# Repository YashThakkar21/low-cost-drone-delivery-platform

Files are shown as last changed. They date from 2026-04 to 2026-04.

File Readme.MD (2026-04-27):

# Low-Cost Drone Delivery Platform

A modular, open-source payload delivery add-on for commodity drone platforms. Designed and evaluated as part of an independent work project at Princeton University.

## Overview

This system attaches to an existing drone airframe and autonomously releases a payload when the drone descends to within one foot of the ground, detected via an HC-SR04 ultrasonic sensor. Two door mechanisms are provided and evaluated: a conventional hinged door and a sliding door.

| Mechanism | Success Rate | Servo | Flight Tested |
|---|---|---|---|
| Hinged door | 28% (7/25) | 1× MG996R | No |
| Sliding door | 84% (21/25) | 2× SG90 | Yes (8/10) |

The sliding door is the recommended design.

## Repository Structure

```
low-cost-drone-delivery-platform/
├── written_final_report.pdf    # Full research paper
├── conventional_door.ino       # Arduino firmware for hinged door
├── sliding_door.ino            # Arduino firmware for sliding door
├── payload_cad_files/          # Payload enclosure (upper + lower modules)
├── hinged_door_cad_files/      # Hinged door mechanism CAD
├── sliding_door_cad_files/     # Sliding door mechanism CAD (modified panels)
└── component_mounts_cad_files/ # Arduino/breadboard mount, sensor case
```

## Hardware Requirements

| Component | Quantity |
|---|---|
| Drone with landing gear rails (e.g. Holybro X500 V2) | 1 |
| Arduino Uno | 1 |
| HC-SR04 ultrasonic sensor | 1 |
| SG90 servo motor (sliding door) | 2 |
| MG996R servo motor (hinged door) | 1 |
| 9V battery + connector | 1 |
| PLA filament (for 3D printing) | — |

## Setup

1. **Print** all CAD files in `payload_cad_files/`, `sliding_door_cad_files/`, and `component_mounts_cad_files/` using standard PLA.
2. **Assemble** the two-module enclosure: seat the Arduino and breadboard in the upper module, install the door mechanism in the lower module, and connect via the screw joint.
3. **Wire** the HC-SR04 to Arduino pins 7 (Trig) and 8 (Echo). Connect SG90 servos to pins 9 and 10. Power via 9V battery.
4. **Flash** `sliding_door.ino` to the Arduino using the Arduino IDE.
5. **Mount** the enclosure onto the drone's landing gear arms using the printed rail mount.

The door triggers automatically when the sensor reads ≤ 30.48 cm (1 ft) from the ground and closes after 10 seconds.

## Flight Platform

Any drone capable of carrying the payload system (~1.4 lb) can be used. This project was developed and tested on the **Holybro X500 V2** with a **Pixhawk 6C** running **PX4 firmware**, configured via **QGroundControl**.

## Paper

Full design details, evaluation methodology, and results are available in [`written_final_report.pdf`](./written_final_report.pdf). Topics covered include the iterative CAD design process (7 enclosure versions), bench reliability testing, flight trials, cost analysis, and a comparison against existing commercial and open-source platforms.

## License

Open-source. All CAD files and firmware are free to use, modify, and distribute.

---

*Princeton University — Department of Computer Science — Spring 2026*  
*Advisor: Professor David August*

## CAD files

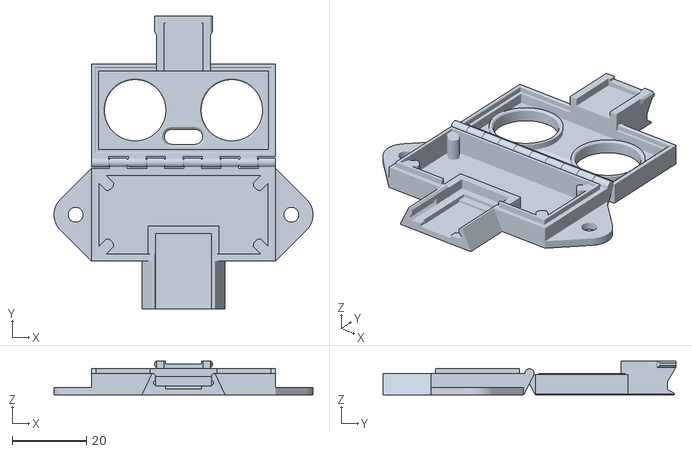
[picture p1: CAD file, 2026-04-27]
component_mounts_cad_files/ultrasonic_sensor_holder.stl
69.7 x 78.7 x 9.10

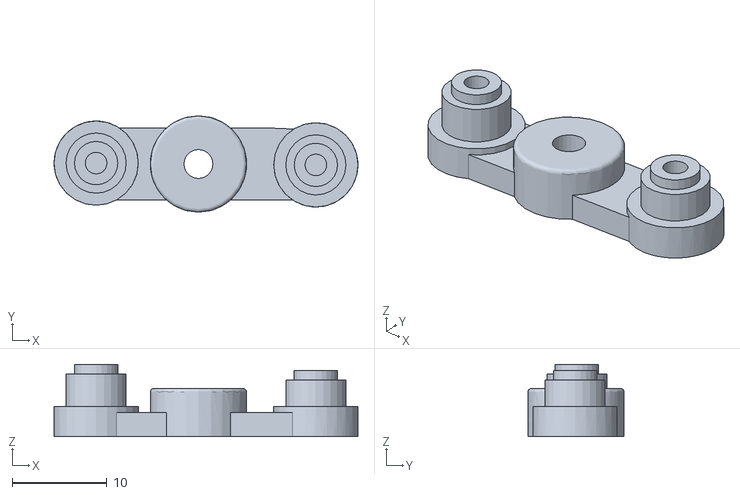
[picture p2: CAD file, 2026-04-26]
hinged_door_cad_files/output_arm.stl
32.1 x 10.2 x 7.62

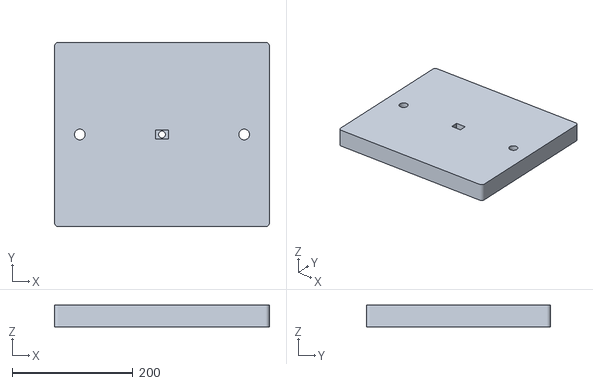
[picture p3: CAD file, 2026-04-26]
payload_cad_files/drone_mount.stl
355.6 x 304.8 x 35.6

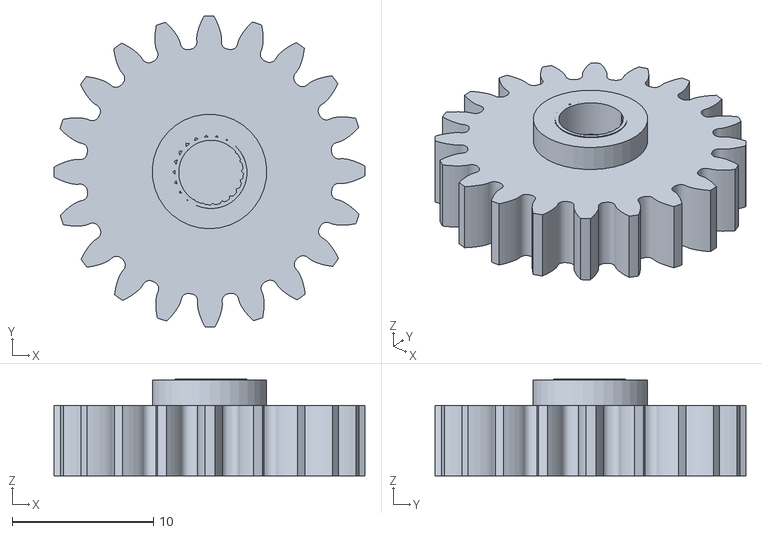
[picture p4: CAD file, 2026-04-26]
sliding_door_cad_files/gear.stl
22.0 x 22.0 x 6.86

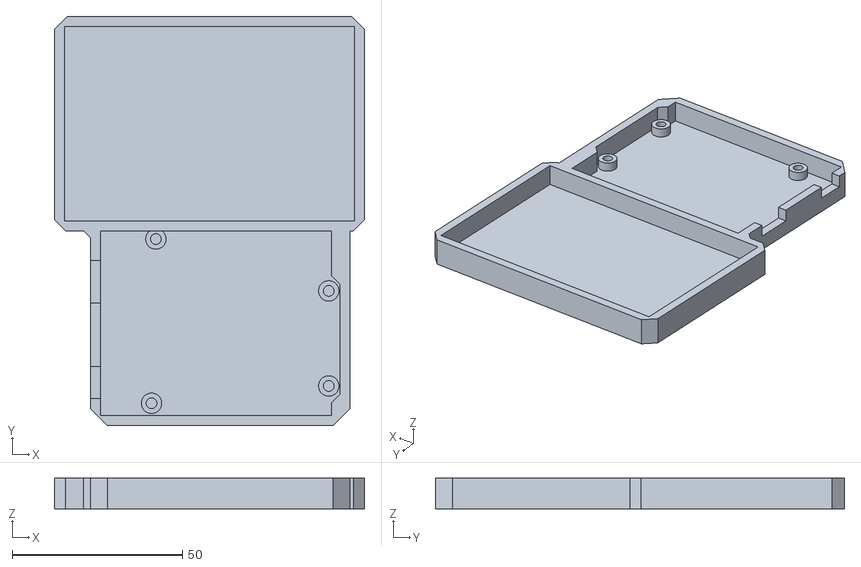
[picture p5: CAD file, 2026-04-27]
component_mounts_cad_files/Arduino_and_breadboard_holder.stl
91.1 x 120.2 x 9.00

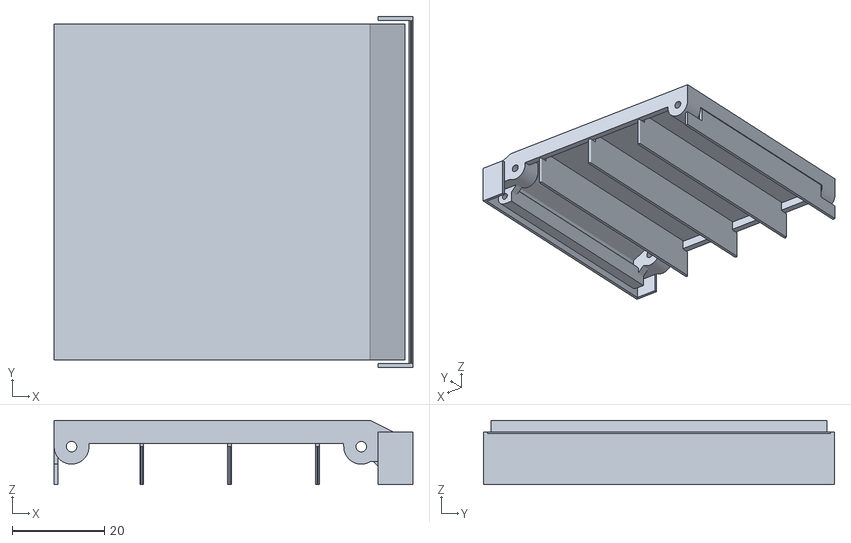
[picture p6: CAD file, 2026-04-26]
hinged_door_cad_files/door.stl
77.9 x 76.2 x 14.0

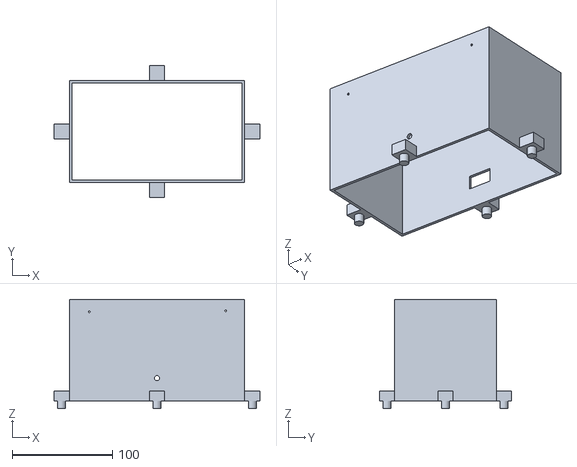
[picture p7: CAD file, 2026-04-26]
payload_cad_files/payload_sliding_bottom_module.stl
205.7 x 132.1 x 109.2

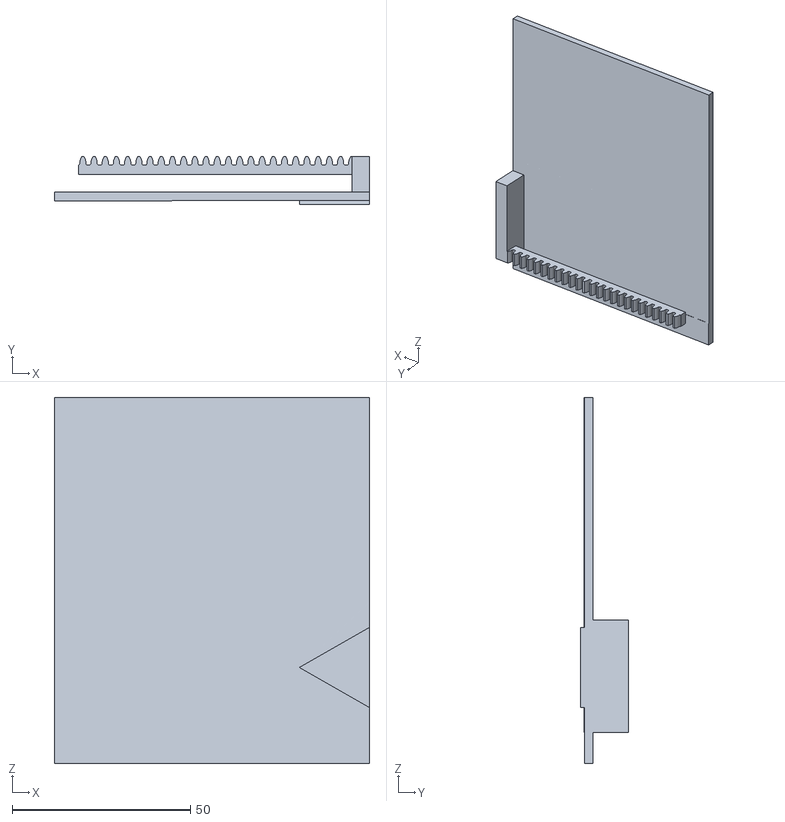
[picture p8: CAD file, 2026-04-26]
sliding_door_cad_files/door.stl
88.4 x 13.3 x 102.6

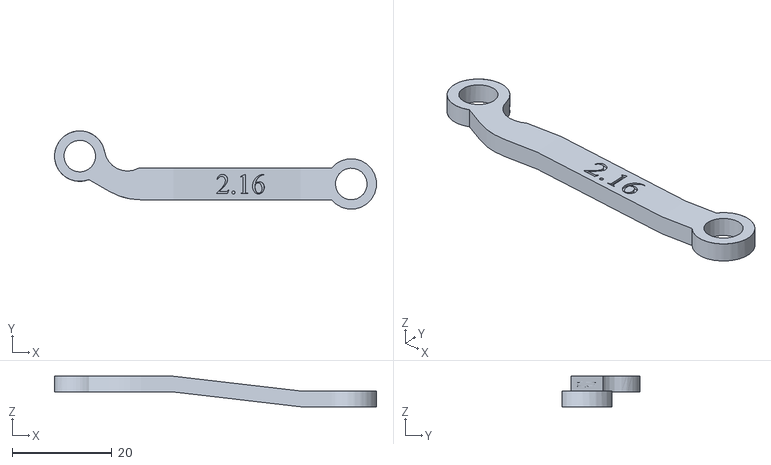
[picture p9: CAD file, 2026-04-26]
hinged_door_cad_files/right_support_arm.STL
64.7 x 15.7 x 6.13

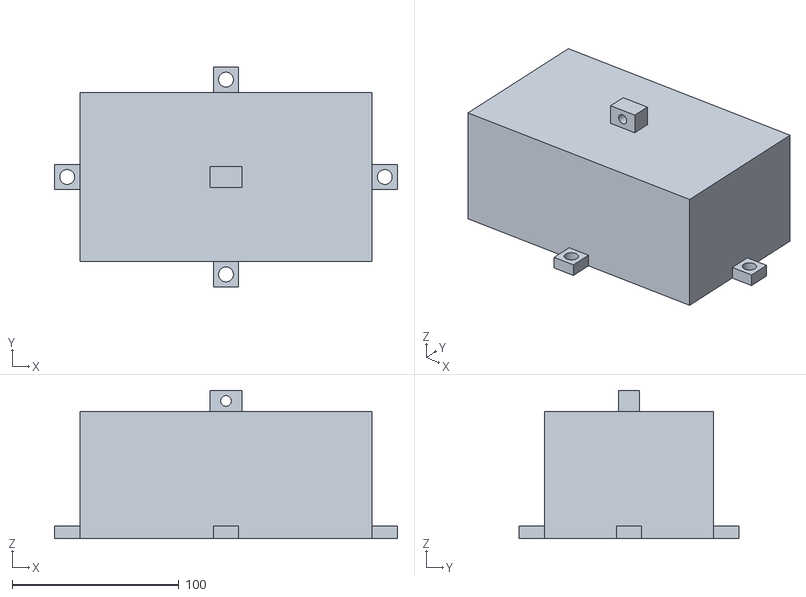
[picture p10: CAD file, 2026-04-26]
payload_cad_files/payload_top_module.stl
205.7 x 132.1 x 88.9

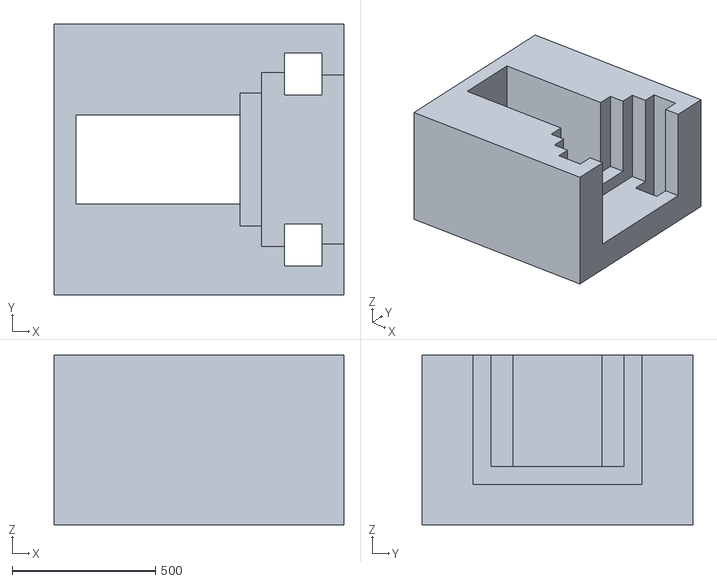
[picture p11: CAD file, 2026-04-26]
sliding_door_cad_files/motor_mount.stl
1010.9 x 945.1 x 591.8

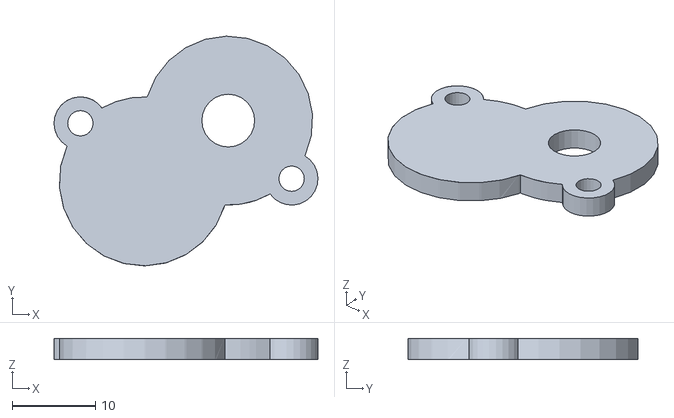
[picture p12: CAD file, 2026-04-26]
hinged_door_cad_files/gear_case_cover.stl
31.7 x 27.6 x 2.54

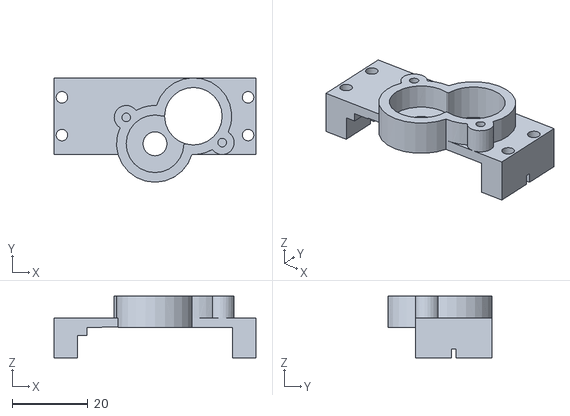
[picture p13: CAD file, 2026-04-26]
hinged_door_cad_files/gear_case.stl
53.5 x 27.6 x 16.4

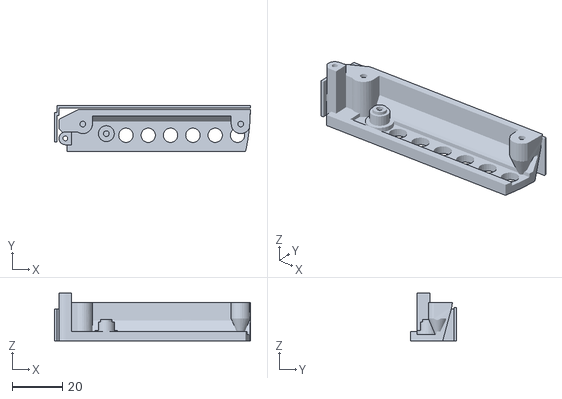
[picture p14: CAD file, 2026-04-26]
hinged_door_cad_files/front_l.stl
78.0 x 18.1 x 19.0

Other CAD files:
payload_cad_files/payload_hinged_bottom_module.stl
hinged_door_cad_files/arm_support.stl
hinged_door_cad_files/double_bone.stl
hinged_door_cad_files/single_bone.stl
hinged_door_cad_files/front_r.stl
hinged_door_cad_files/gear.stl
hinged_door_cad_files/hinges.stl
hinged_door_cad_files/left_support_arm.STL
hinged_door_cad_files/output_gear.stl

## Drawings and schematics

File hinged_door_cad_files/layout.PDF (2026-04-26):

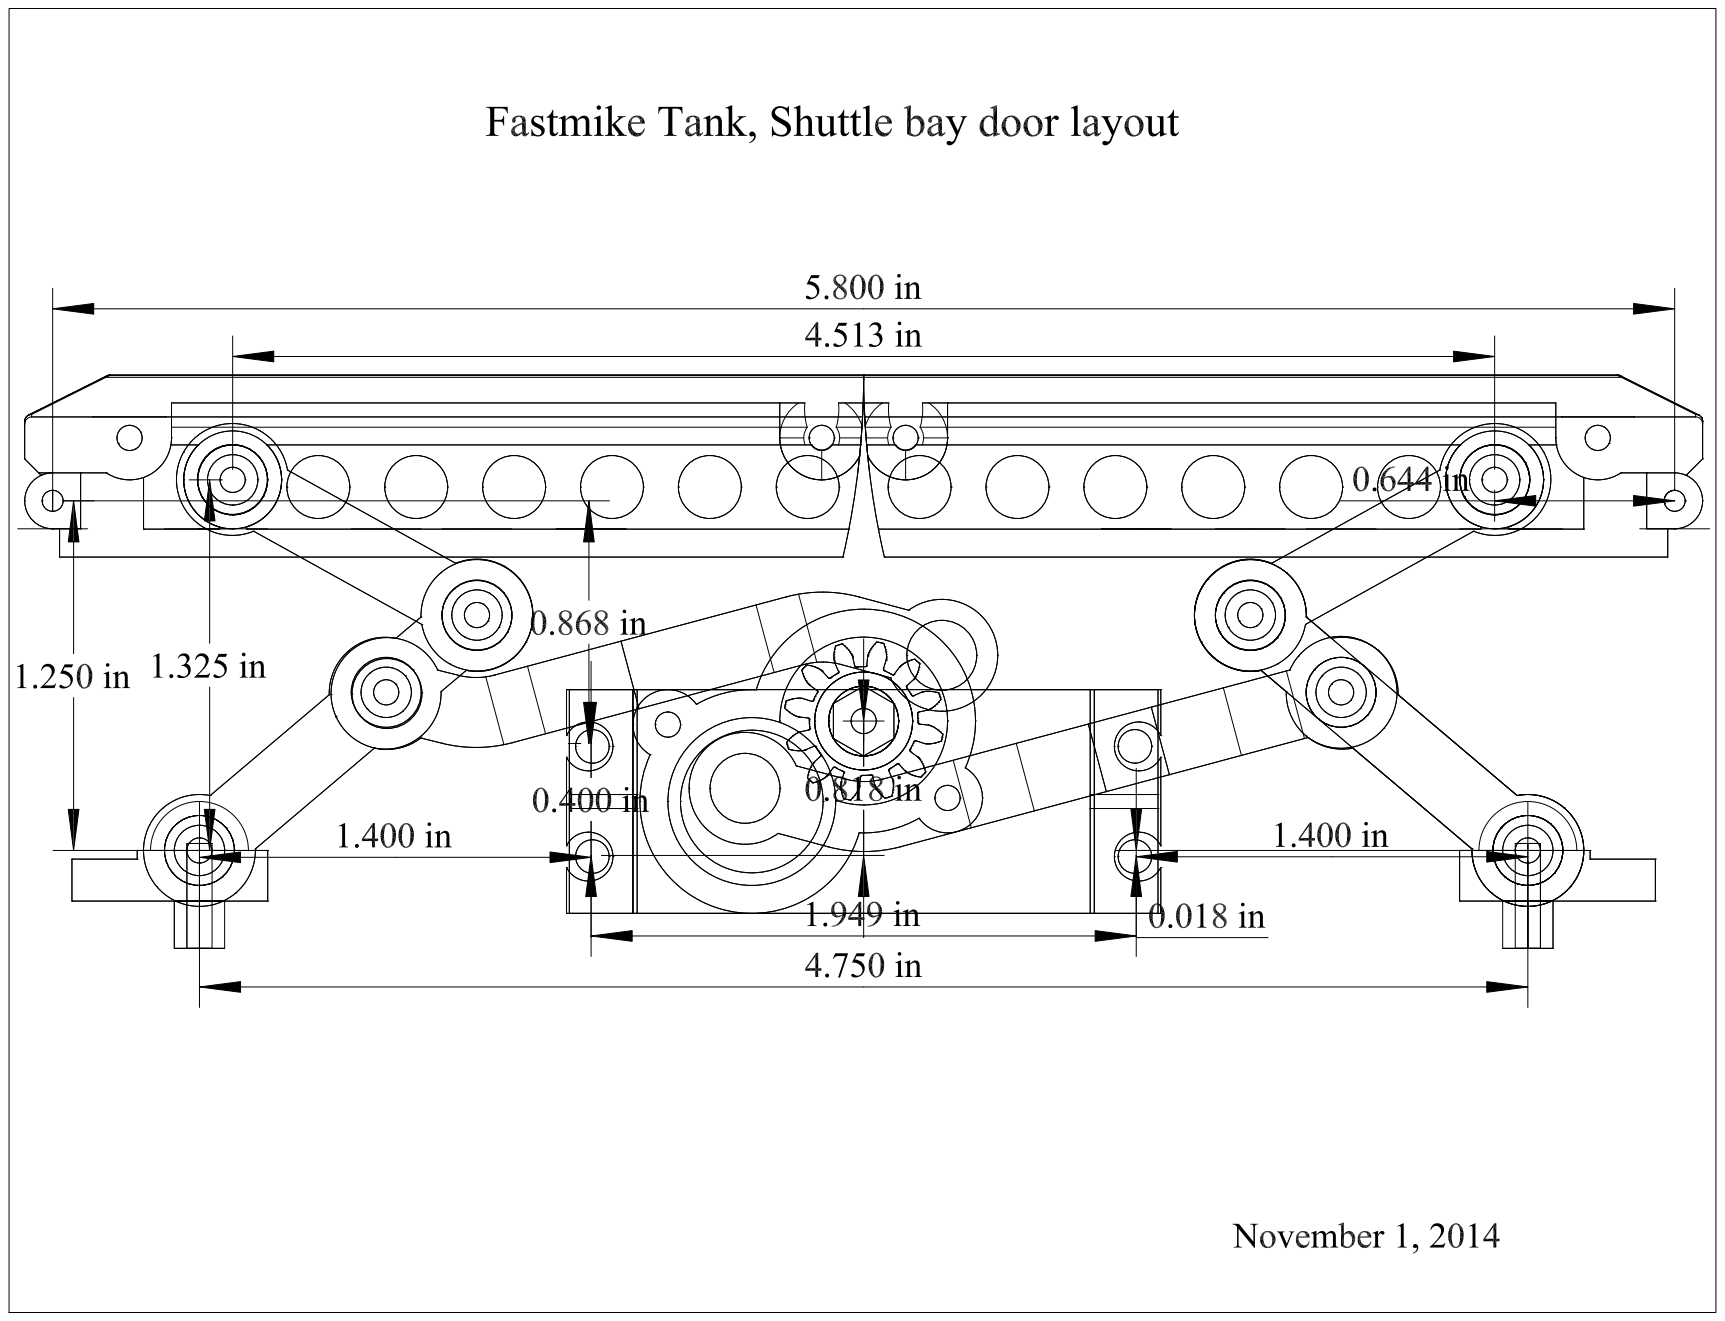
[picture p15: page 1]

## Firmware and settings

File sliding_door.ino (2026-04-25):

#include <Servo.h>

Servo doorServo1;
Servo doorServo2;

// HC-SR04 pins
const int trigPin = 7;
const int echoPin = 8;

// 1 foot in cm
const float detectionThreshold = 30.48;

bool doorsOpen = false;
unsigned long doorOpenedAt = 0;
const unsigned long doorOpenDuration = 10000; // 10 seconds

void setup() {
  Serial.begin(9600);

  doorServo1.attach(9);
  doorServo2.attach(10);

  // Start with doors closed
  doorServo1.write(0);
  doorServo2.write(180); // Mirrored for opposite side of door

  pinMode(trigPin, OUTPUT);
  pinMode(echoPin, INPUT);

  Serial.println("Door system ready.");
}

float getDistance() {
  digitalWrite(trigPin, LOW);
  delayMicroseconds(2);
  digitalWrite(trigPin, HIGH);
  delayMicroseconds(10);
  digitalWrite(trigPin, LOW);

  long duration = pulseIn(echoPin, HIGH, 30000); // 30ms timeout
  if (duration == 0) return -1;
  return (duration * 0.0343) / 2;
}

void openDoors() {
  doorServo1.write(180);
  doorServo2.write(0); // Mirrored open position
  doorsOpen = true;
  doorOpenedAt = millis();
  Serial.println("Doors OPENED");
}

void closeDoors() {
  doorServo1.write(0);
  doorServo2.write(180); // Mirrored closed position
  doorsOpen = false;
  Serial.println("Doors CLOSED");
}

void loop() {
  float distance = getDistance();

  // If something is within 1 foot and doors are closed, open them
  if (distance > 0 && distance < detectionThreshold && !doorsOpen) {
    openDoors();
  }

  // If doors are open and 10 seconds have passed, close them
  if (doorsOpen && (millis() - doorOpenedAt >= doorOpenDuration)) {
    closeDoors();
  }

  delay(100);
}

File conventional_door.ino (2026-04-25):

#include <Servo.h>

Servo doorServo;

// HC-SR04 pins
const int trigPin = 7;
const int echoPin = 8;

// 1 foot in cm
const float detectionThreshold = 30.48;

bool doorOpen = false;
unsigned long doorOpenedAt = 0;
const unsigned long doorOpenDuration = 10000; // 10 seconds

void setup() {
  Serial.begin(9600);

  doorServo.attach(9);
  doorServo.write(0); // Start closed

  pinMode(trigPin, OUTPUT);
  pinMode(echoPin, INPUT);
}

float getDistance() {
  digitalWrite(trigPin, LOW);
  delayMicroseconds(2);
  digitalWrite(trigPin, HIGH);
  delayMicroseconds(10);
  digitalWrite(trigPin, LOW);

  long duration = pulseIn(echoPin, HIGH, 30000);
  if (duration == 0) return -1;
  return (duration * 0.0343) / 2;
}

void openDoor() {
  doorServo.write(180);
  doorOpen = true;
  doorOpenedAt = millis();
}

void closeDoor() {
  doorServo.write(0);
  doorOpen = false;
}

void loop() {
  float distance = getDistance();

  if (distance > 0 && distance < detectionThreshold && !doorOpen) {
    openDoor();
  }

  if (doorOpen && (millis() - doorOpenedAt >= doorOpenDuration)) {
    closeDoor();
  }

  delay(100);
}

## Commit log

2026-04-25 arduino implementation code
2026-04-26 cad files
    [arm_support.stl, door.stl, double_bone.stl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]
2026-04-27 readme and cad files
    [Arduino_and_breadboard_holder.stl, ultrasonic_sensor_holder.stl]
